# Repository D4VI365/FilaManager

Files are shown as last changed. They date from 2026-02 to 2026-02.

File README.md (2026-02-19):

# 5-Spool Heated Drybox & AMS-Ready Controller

This project features an **Active Heated Drybox** designed for 5 filament spools, managed by a **BigTreeTech SKR 3** 3D printer motherboard. The system ensures filaments remain dehumidified and print-ready, with a hardware foundation prepared for future AMS (Automatic Material System) expansion.

---

## Technical Specifications
* **Controller:** BigTreeTech SKR 3 (Marlin 2.1.x Firmware).
* **Capacity:** 5 standard spools (up to 200mm diameter).
* **Heating:** 24V PTC Heater with a 5015 Blower Fan for active air circulation.
* **Interface:** LCD 12864 Graphic Display with rotary encoder.
* **Sensor:** Trianglelab NTC 100K B3950 Thermistor (M3 Threaded version).
* **External Electronics:** Housed in a dedicated ventilated base to prevent overheating of the MCU and PSU.

---

# Repository Structure
* `/CAD`: 3D models (STL/STEP) for the enclosure corners, electronics base, and internal spool rollers.
* `/Firmware`: Pre-configured Marlin source code and compiled `firmware.bin`.

| Component | Quantity | Total Price USD | Supplier |
| :--- | :---: | :---: | :--- |
| Screen with controller | 1 | 17,42 | Aliexpress |
| M3 20mm Standoff | 4 | 5,15 | Aliexpress |
| Rubber Hose 2mm | 3m | 4,26 | Aliexpress |
| 608RS Bearings | 20 | 11,53 | Aliexpress |
| Nema 17 Motors | 5 | 50,3 | Aliexpress |
| 24V/20A Power Supply | 1 | 41,95 | Aliexpress |
| SKR3 control board + drivers | 1 | 77,29 | Aliexpress |
| 24V/250W PTC heater | 1 | 9,35 | Aliexpress |
| PTFE Tube Connector | 10 | 6,76 | Aliexpress |
| power plug | 1 | 2,31 | Aliexpress |
| B3950 heat sensor | 2 | 16,1 | Aliexpress |
| 4010 fan | 3 | 8,91 | Aliexpress |
| 505020 fan | 2 | 9,72 | Aliexpress |
| dual drive extruder | 5 | 43,9 | Aliexpress |
| PC Panels | custom | 81,09 | PannelliPlastica |
| **Total price:** | | **386,04** | |
| **Total price+shipping** | | **395,44** | |

> All the screws, heat press inserts and nuts I will buy them by myself to stay under 400 USD

---
## Images
FullAssembly
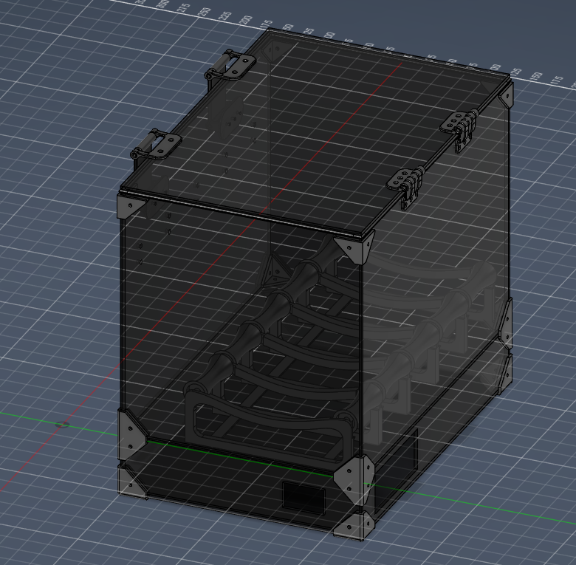
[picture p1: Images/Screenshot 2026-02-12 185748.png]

Latches
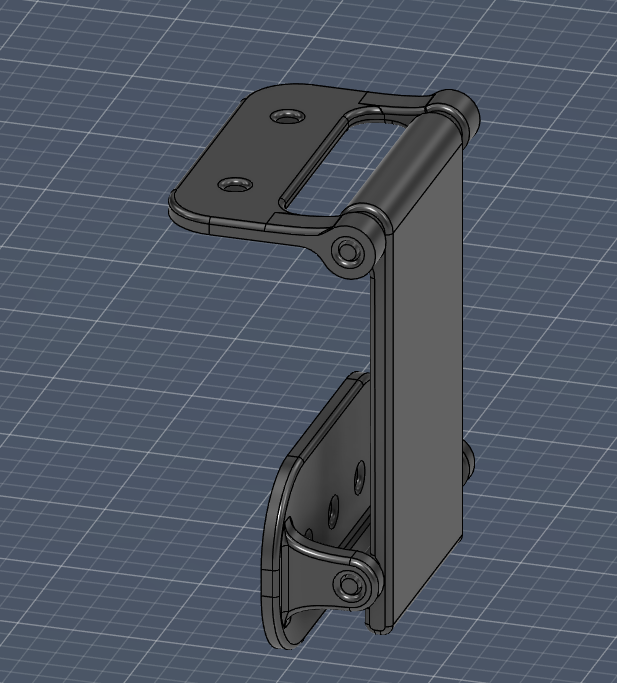
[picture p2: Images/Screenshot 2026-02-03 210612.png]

Hinges
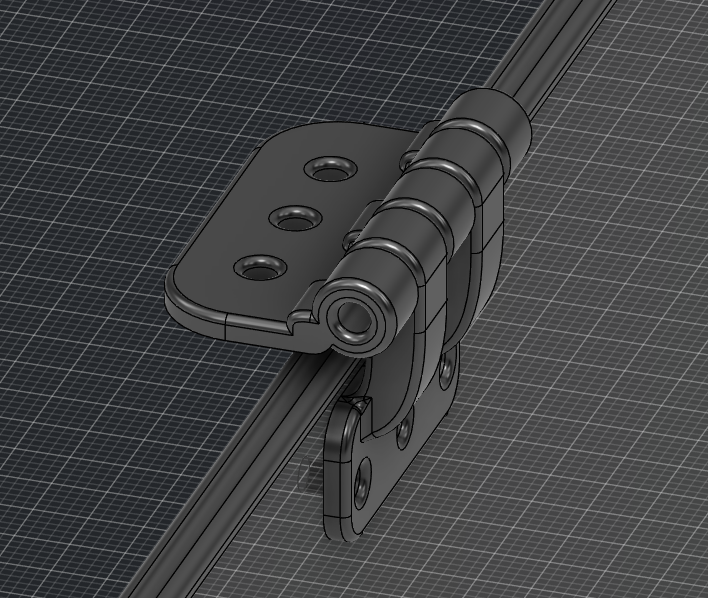
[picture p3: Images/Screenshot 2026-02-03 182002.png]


## Firmware Configuration (Marlin)
The system utilizes a specialized build of Marlin. Key modifications in `Configuration.h` include reassigning the Heated Bed output to drive the Chamber Heater:

```cpp
// Core settings for the Drybox
#define MOTHERBOARD BOARD_BTT_SKR_V3_0
#define TEMP_SENSOR_CHAMBER 1        // NTC 100K B3950
#define HEATER_CHAMBER_PIN HEATER_BED_PIN 

// Display Settings
#define REPRAP_DISCOUNT_FULL_GRAPHIC_SMART_CONTROLLER

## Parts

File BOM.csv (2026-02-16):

Component | Quantity | Total Price USD | Supplier | Link
Screen with controller | 1 | 17.42 | Aliexpress | https://www.aliexpress.com/item/1005007358498758.html?spm=a2g0o.cart.0.0.202b38daDUaazp&mp=1
M3 20mm Standoff | 4 | 5.15 | Aliexpress | https://www.aliexpress.com/item/1005003757527746.html?spm=a2g0o.cart.0.0.202b38daDUaazp&mp=1
Rubber Hose 2mm | 3m | 4.26 | Aliexpress | https://www.aliexpress.com/item/1005008095575859.html?spm=a2g0o.cart.0.0.202b38daDUaazp&mp=1
608RS Bearings | 20 | 11.53 | Aliexpress | https://www.aliexpress.com/item/289770267.html?spm=a2g0o.cart.0.0.202b38daDUaazp&mp=1
Nema 17 Motors | 5 | 50.3 | Aliexpress | https://www.aliexpress.com/item/1005009083189923.html?spm=a2g0o.cart.0.0.202b38daDUaazp&mp=1
24V/20A Power Supply | 1 | 41.95 | Aliexpress | https://www.aliexpress.com/item/1005005687347846.html?spm=a2g0o.cart.0.0.202b38daDUaazp&mp=1
SKR3 control board + drivers | 1 | 77.29 | Aliexpress | https://www.aliexpress.com/item/1005008688298885.html?spm=a2g0o.cart.0.0.202b38daDUaazp&mp=1
24V/250W PTC heater | 1 | 9.35 | Aliexpress | https://www.aliexpress.com/item/1005009420069979.html?spm=a2g0o.cart.0.0.202b38daDUaazp&mp=1
PTFE Tube Connector | 10 | 6.76 | Aliexpress | https://www.aliexpress.com/item/1005010058081717.html?spm=a2g0o.cart.0.0.202b38daDUaazp&mp=1
power plug | 1 | 2.31 | Aliexpress | https://www.aliexpress.com/item/1005006361356458.html?mp=1
B3950 heat sensor | 2 | 16.1 | Aliexpress | https://www.aliexpress.com/item/33029709571.html?mp=1
4010 fan | 3 | 8.91 | Aliexpress | https://www.aliexpress.com/item/1005006306536871.html?spm=a2g0o.cart.0.0.202b38daDUaazp&mp=1
505020 fan | 2 | 9.72 | Aliexpress | https://www.aliexpress.com/item/1005008620165308.html?spm=a2g0o.cart.0.0.202b38daDUaazp&mp=1
dual drive extruder | 5 | 43.9 | Aliexpress | https://www.aliexpress.com/item/1005007306772900.html?spm=a2g0o.cart.0.0.202b38daDUaazp&mp=1
PC Panels | custom | 81.09 | PannelliPlastica | https://pannelliplastica.it/
Total price: | 386.04
Total price+shipping | 395.44
All the screws, heat press inserts and nuts I will buy them by myself to stay under 400 USD

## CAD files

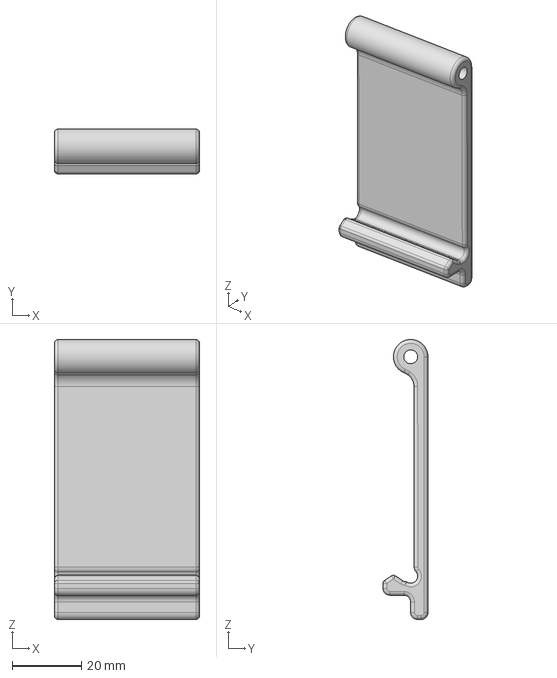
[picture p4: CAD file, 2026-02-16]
CAD/STEP/Latches/MainBody.step
42.0 x 13.0 x 80.9 mm

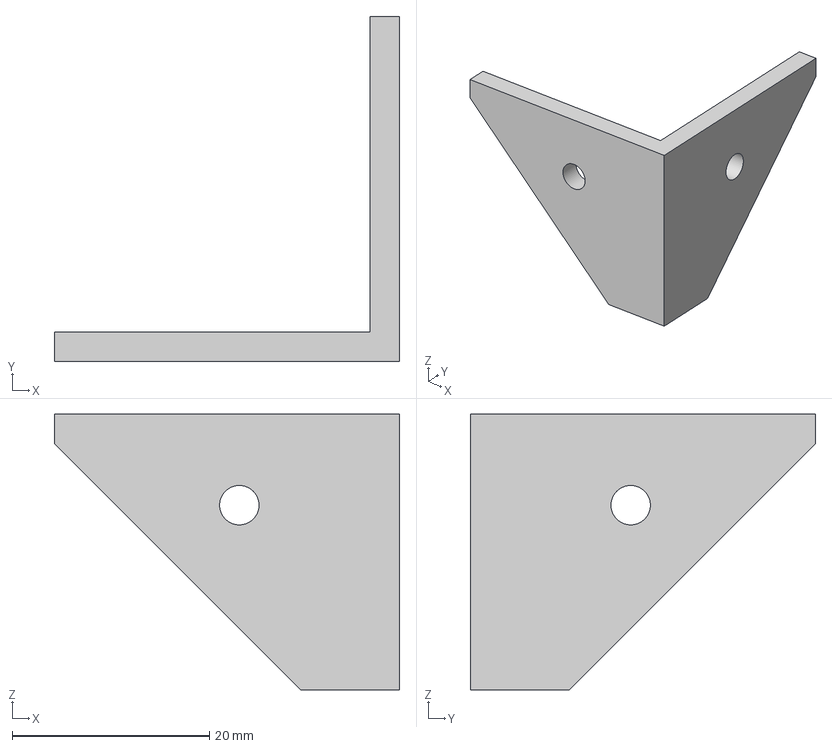
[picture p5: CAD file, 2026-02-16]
CAD/STEP/CornerHolders/TopExternal.step
35.0 x 35.0 x 28.0 mm

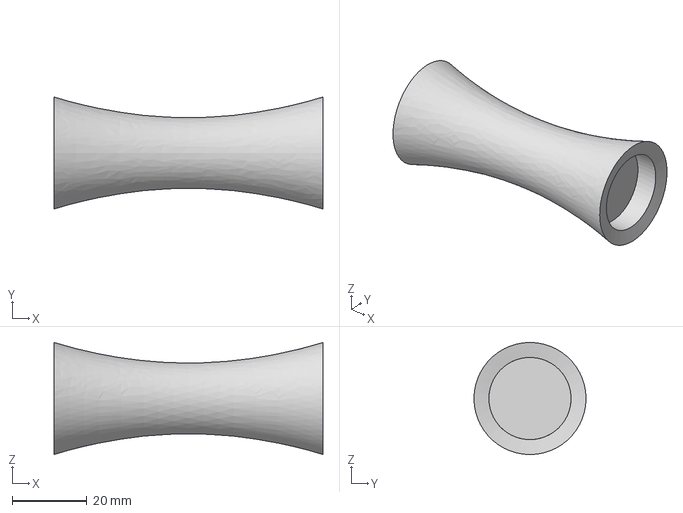
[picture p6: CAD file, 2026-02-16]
CAD/STEP/FilamentHolders/SpoolRoller.step
72.0 x 30.0 x 30.0 mm

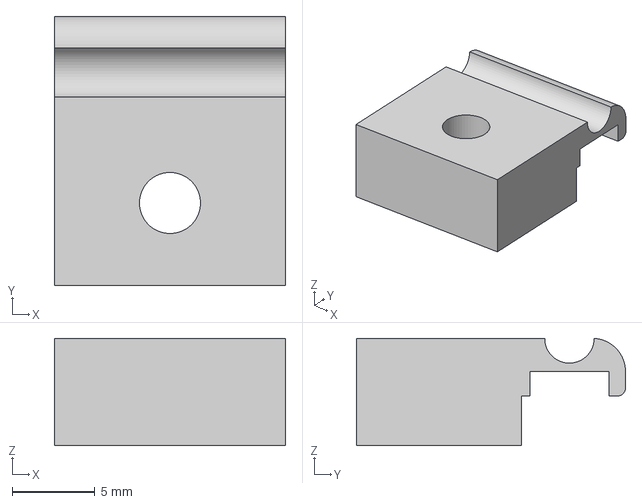
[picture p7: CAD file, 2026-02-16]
CAD/STEP/GasketHolder/HeatSensorHolder.step
14.0 x 16.3 x 6.50 mm

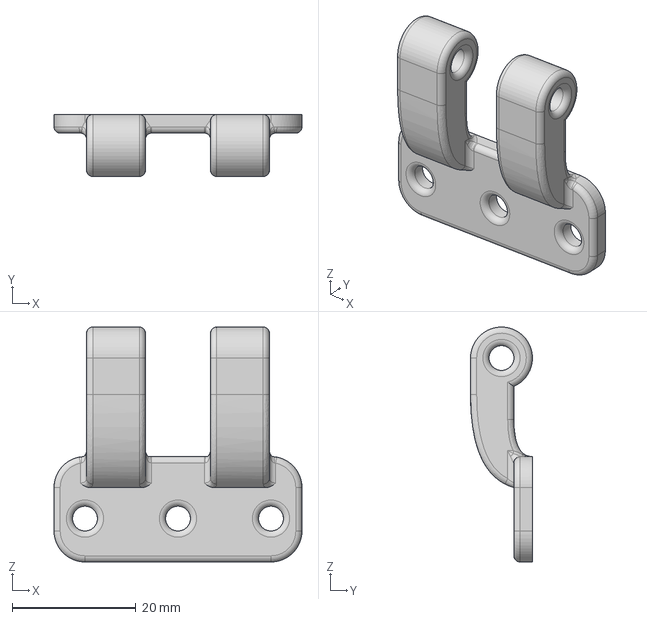
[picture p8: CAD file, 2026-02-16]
CAD/STEP/Hinges/LowerHinge.step
40.0 x 10.0 x 37.9 mm

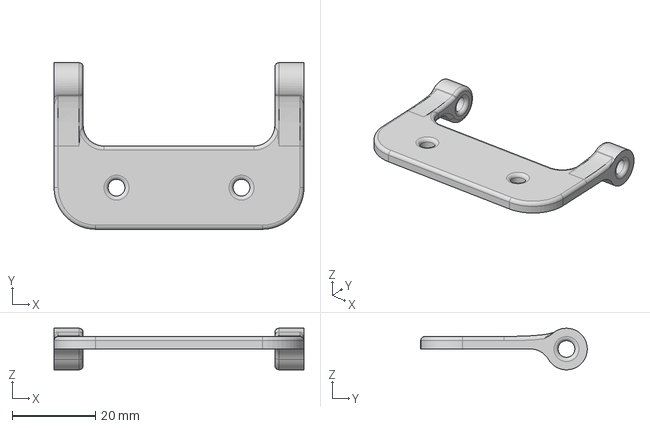
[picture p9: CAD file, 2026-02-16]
CAD/STEP/Latches/UpperHolder.step
60.0 x 40.0 x 9.99 mm

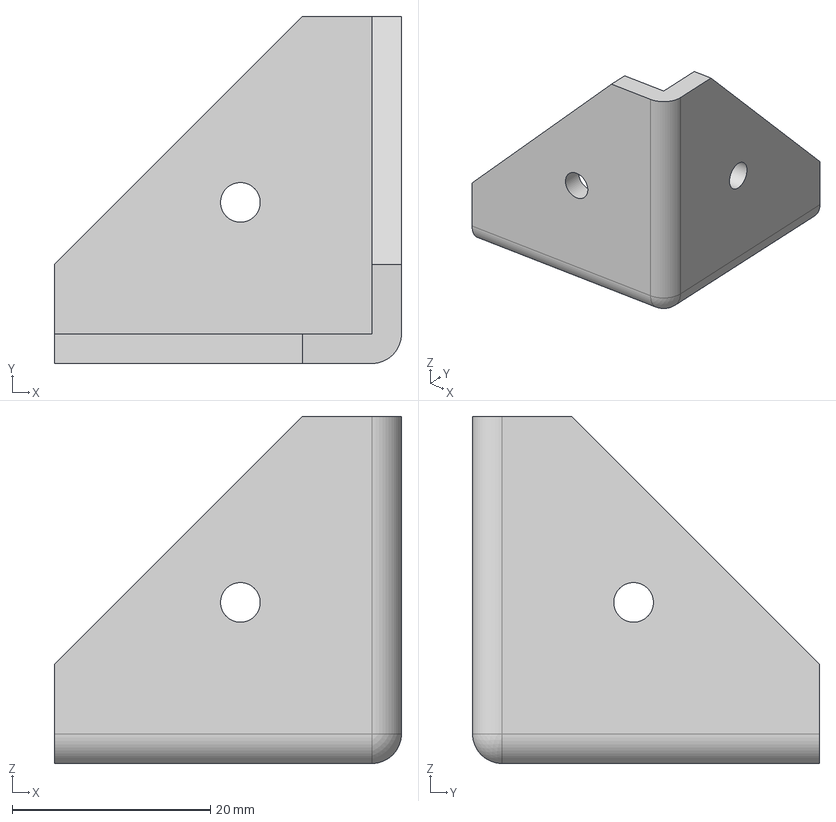
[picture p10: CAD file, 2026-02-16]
CAD/STEP/CornerHolders/ExternalCorner.step
35.0 x 35.0 x 35.0 mm

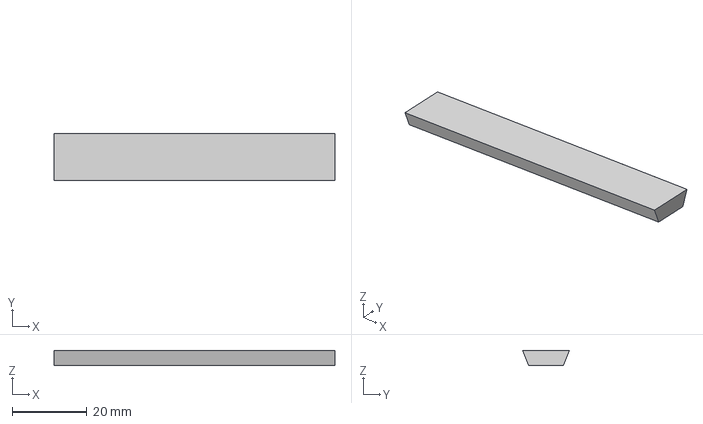
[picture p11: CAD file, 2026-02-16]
CAD/STEP/FilamentHolders/Brace.step
75.1 x 12.5 x 4.00 mm

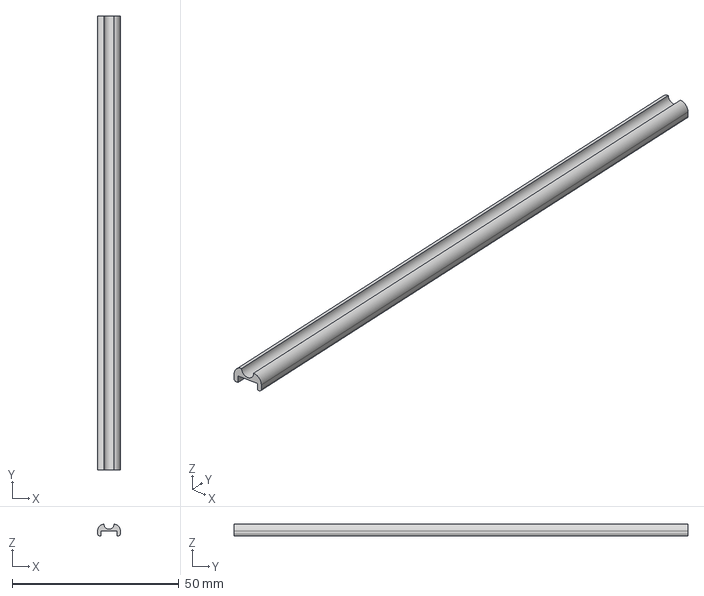
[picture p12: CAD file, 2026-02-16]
CAD/STEP/GasketHolder/SideHalf.step
6.80 x 136.0 x 3.50 mm

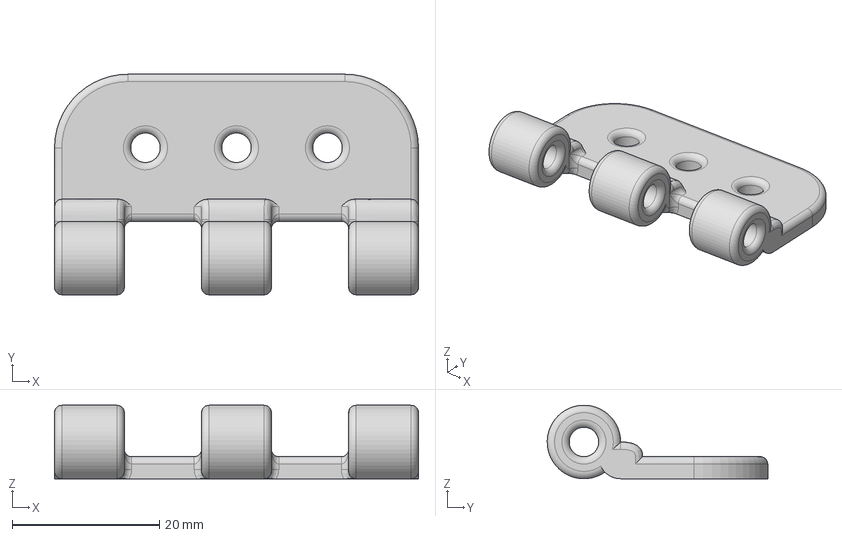
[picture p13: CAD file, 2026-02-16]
CAD/STEP/Hinges/UpperHinge.step
49.5 x 30.0 x 10.00 mm

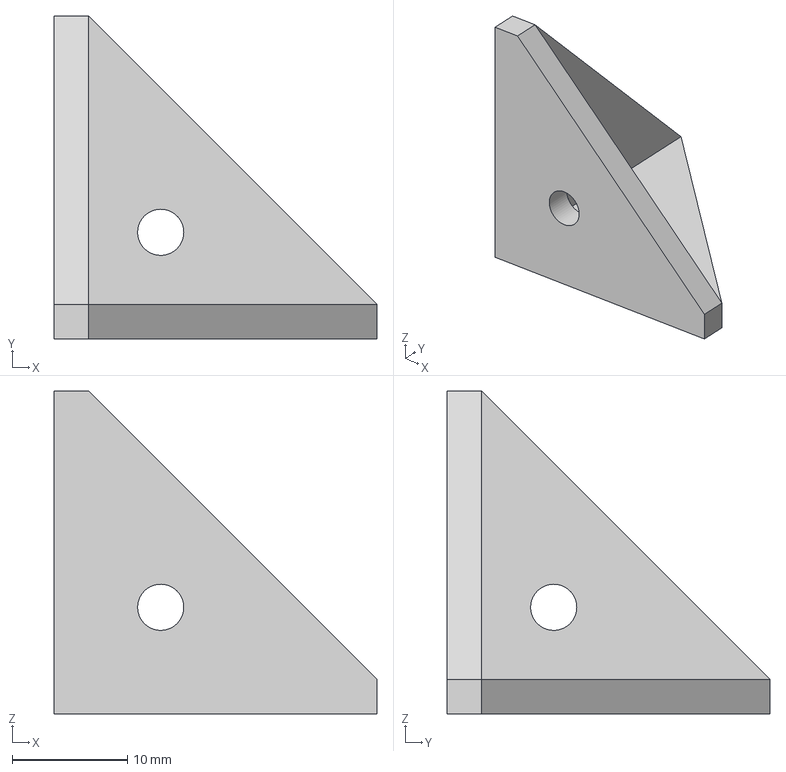
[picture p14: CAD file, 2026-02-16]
CAD/STEP/CornerHolders/InternalCorner.step
28.0 x 28.0 x 28.0 mm

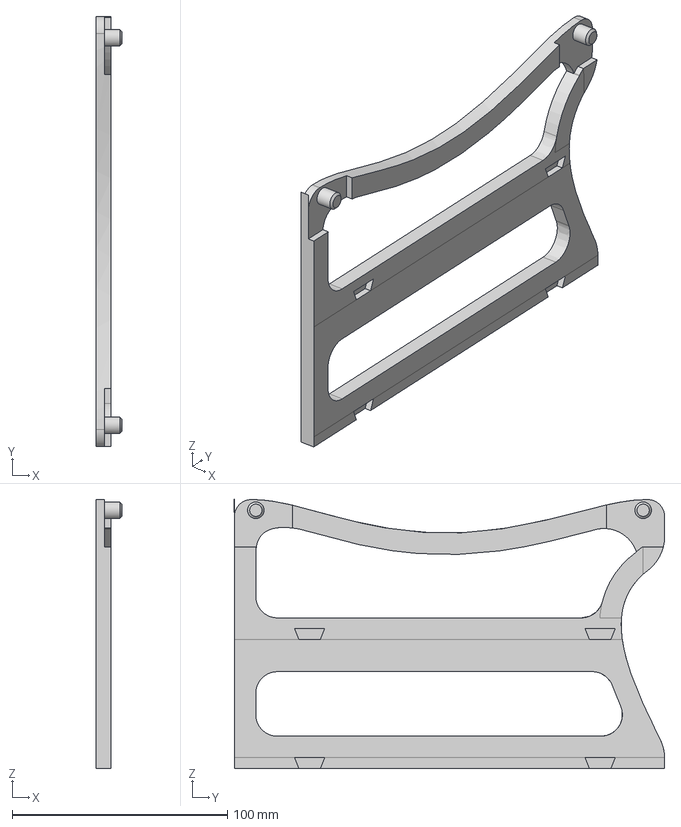
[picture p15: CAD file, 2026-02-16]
CAD/STEP/FilamentHolders/LSideHolder.step
12.0 x 200.0 x 125.0 mm

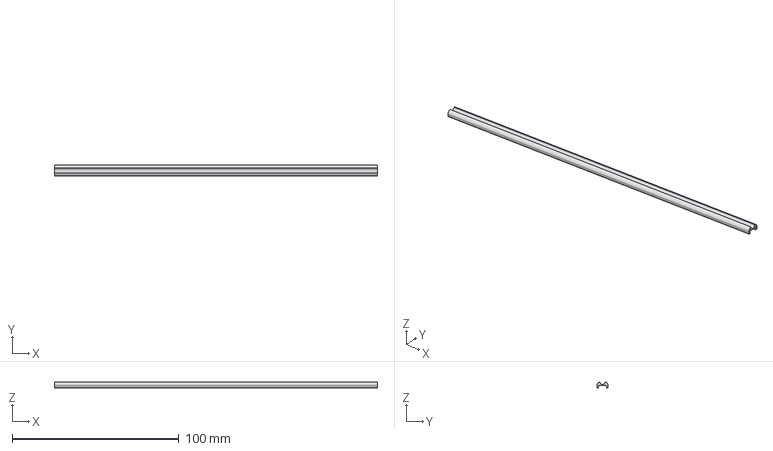
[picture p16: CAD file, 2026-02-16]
CAD/STEP/GasketHolder/FrontHalf.step
194.0 x 6.80 x 3.50 mm

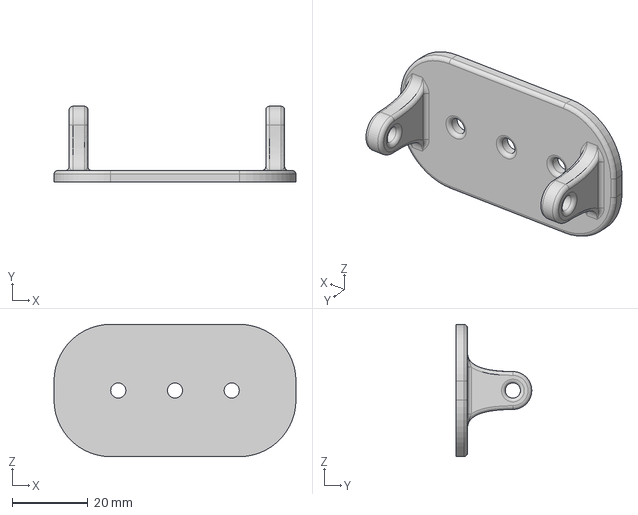
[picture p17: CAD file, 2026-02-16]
CAD/STEP/Latches/LowerHolder.step
64.0 x 20.0 x 35.0 mm

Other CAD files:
CAD/STEP/CornerHolders/DoubleExternal.step
CAD/STEP/FilamentHolders/MiddleHolder.step
CAD/STEP/GasketHolder/Corner.step
CAD/STEP/CornerHolders/TopInternal.step
CAD/STEP/FilamentHolders/BraceSensor.step
CAD/STEP/FilamentHolders/RSideHolder.step
CAD/STEP/GasketHolder/BackHalf.step
CAD/STL/CornerHolders/DoubleExternal.stl
CAD/STL/CornerHolders/ExternalCorner.stl
CAD/STL/CornerHolders/InternalCorner.stl
CAD/STL/CornerHolders/TopExternal.stl
CAD/STL/CornerHolders/TopInternal.stl
CAD/STL/FilamentHolders/Brace.stl
CAD/STL/FilamentHolders/BraceSensor.stl
CAD/STL/FilamentHolders/LSideHolder.stl
CAD/STL/FilamentHolders/MiddleHolder.stl
CAD/STL/FilamentHolders/RSideHolder.stl
CAD/STL/FilamentHolders/SpoolRoller.stl
CAD/STL/GasketHolder/BackHalf.stl
CAD/STL/GasketHolder/Corner.stl
CAD/STL/GasketHolder/FrontHalf.stl
CAD/STL/GasketHolder/HeatSensorHolder.stl
CAD/STL/GasketHolder/SideHalf.stl
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

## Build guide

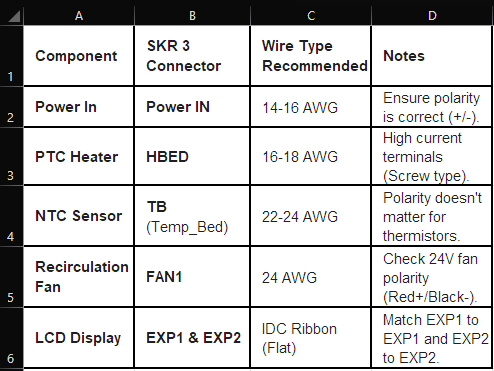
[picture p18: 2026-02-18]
Electronics/Wiring diagram.png

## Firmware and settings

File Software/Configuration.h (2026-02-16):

// Impostazione Scheda Madre
#define MOTHERBOARD BOARD_BTT_SKR_V3_0

// Impostazione Sensore Temperatura (NTC 100K B3950 Trianglelab)
#define TEMP_SENSOR_CHAMBER 1 

// Limiti di Sicurezza
#define CHAMBER_HEATER_MAXTEMP 75
#define CHAMBER_MINTEMP 5

// Assegnazione Pin Riscaldatore (Usa l'uscita del Bed per il PTC)
#define HEATER_CHAMBER_PIN HEATER_BED_PIN 

// Abilitazione Controllo PID per la Camera (per temperatura stabile)
#define PIDTEMPCHAMBER
#if ENABLED(PIDTEMPCHAMBER)
  #define DEFAULT_chamberKp 20.00
  #define DEFAULT_chamberKi 1.00
  #define DEFAULT_chamberKd 100.00
#endif

// ABILITAZIONE DISPLAY (Quello che hai trovato tu)
#define REPRAP_DISCOUNT_FULL_GRAPHIC_SMART_CONTROLLER

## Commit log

2026-02-16 Add CAD models, STL/STEP and configs
    Import CAD assets for the project: add Fusion 360 file (CAD/FilaManager.f3d) and numerous STEP and STL models for CornerHolders, FilamentHolders, GasketHolder, Hinges and Latches. Also add project me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
    [BackHalf.step, BackHalf.stl, Brace.step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]
2026-02-16 Add BOM.csv (Bill of Materials)
    Add initial Bill of Materials file (BOM.csv) to the repository to track components, part numbers, and quantities for the project. This file enables versioning and review of the BOM alongside the sour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
    [BOM.csv]
2026-02-16 Ignore Excel temp file ~$BOM.csv
    Add a .gitignore entry to prevent committing the Excel temporary file `~$BOM.csv` (created while editing BOM.csv). This avoids accidental commits of transient editor/temp files.
2026-02-18 Add wiring diagram and BOM to README
    Add Electronics/Wiring diagram.png and expand README with a parts list (BOM) table including quantities, suppliers and prices, plus total price and total+shipping. Also add a note that screws, insert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
